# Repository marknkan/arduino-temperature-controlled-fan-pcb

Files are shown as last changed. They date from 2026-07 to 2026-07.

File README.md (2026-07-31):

# Arduino Temperature-Controlled Fan PCB

My first manufactured PCB: an Arduino Uno expansion board for a temperature-controlled DC fan with automatic and manual operating modes.

This project developed an earlier breadboard prototype into my first manufactured PCB. It brought together embedded programming, analogue sensing, PWM motor control, user inputs, LCD output, schematic capture, PCB layout, soldering, testing and hardware debugging.

Arduino Uno, Embedded C/C++, KiCad, PCB Design, PWM ADC, and Hardware Debugging

Status — Version 1 tested: The PCB was successfully designed, manufactured and assembled. The controls and several interfaces worked, while bring-up exposed three hardware issues to correct in Version 2: the fan-driver routing, RGB LED pin mapping and LM35 interface

[Powered assembled PCB](docs/images/hardware/pcb-powered-on.jpg)

[Watch the Version 1 prototype demonstration] (https://github.com/marknkan/arduino-temperature-controlled-fan-pcb/releases/tag/v1.0)

# Contents

- Project objectives

- Operating modes

- Hardware

- Main pin assignments

- PCB development

### Schematic

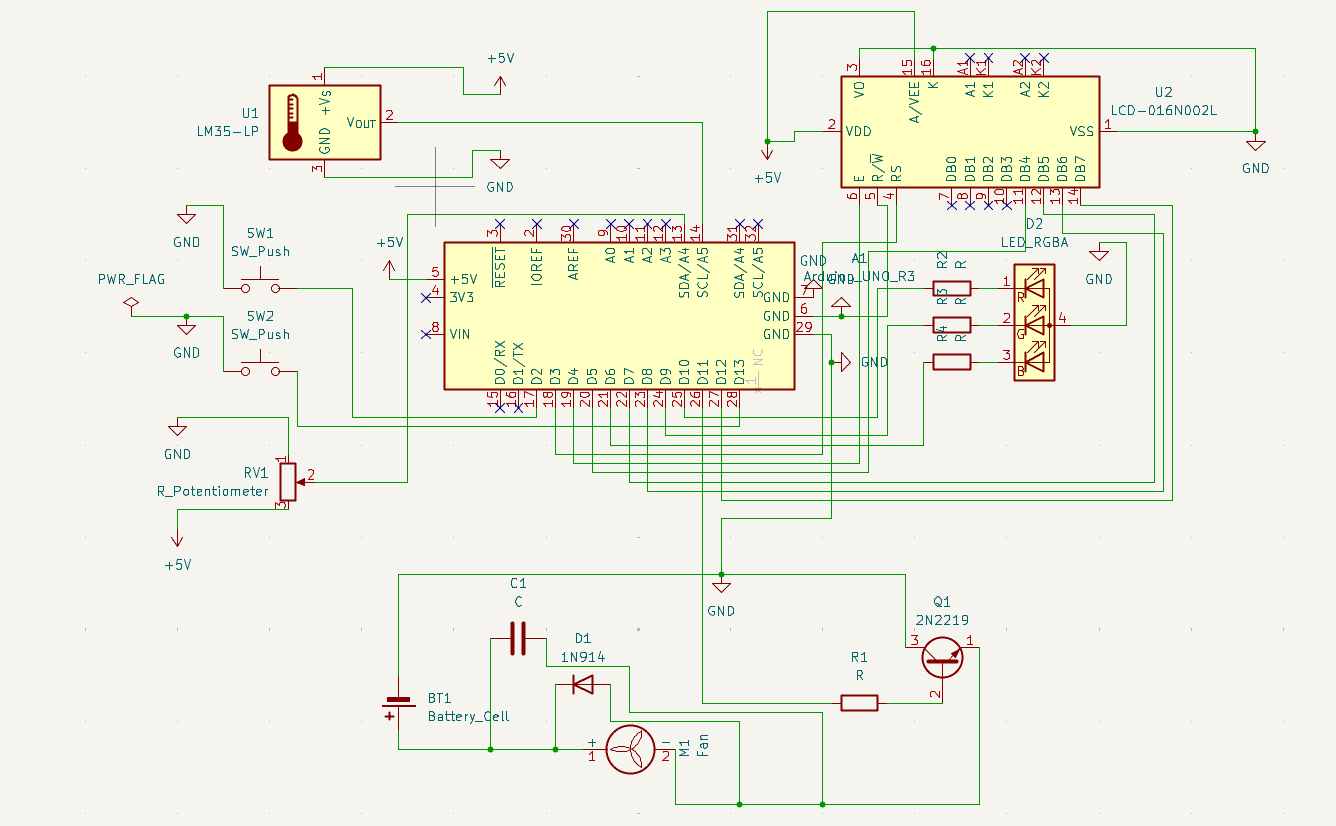
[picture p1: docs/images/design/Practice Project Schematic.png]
KiCad schematic


### PCB layout

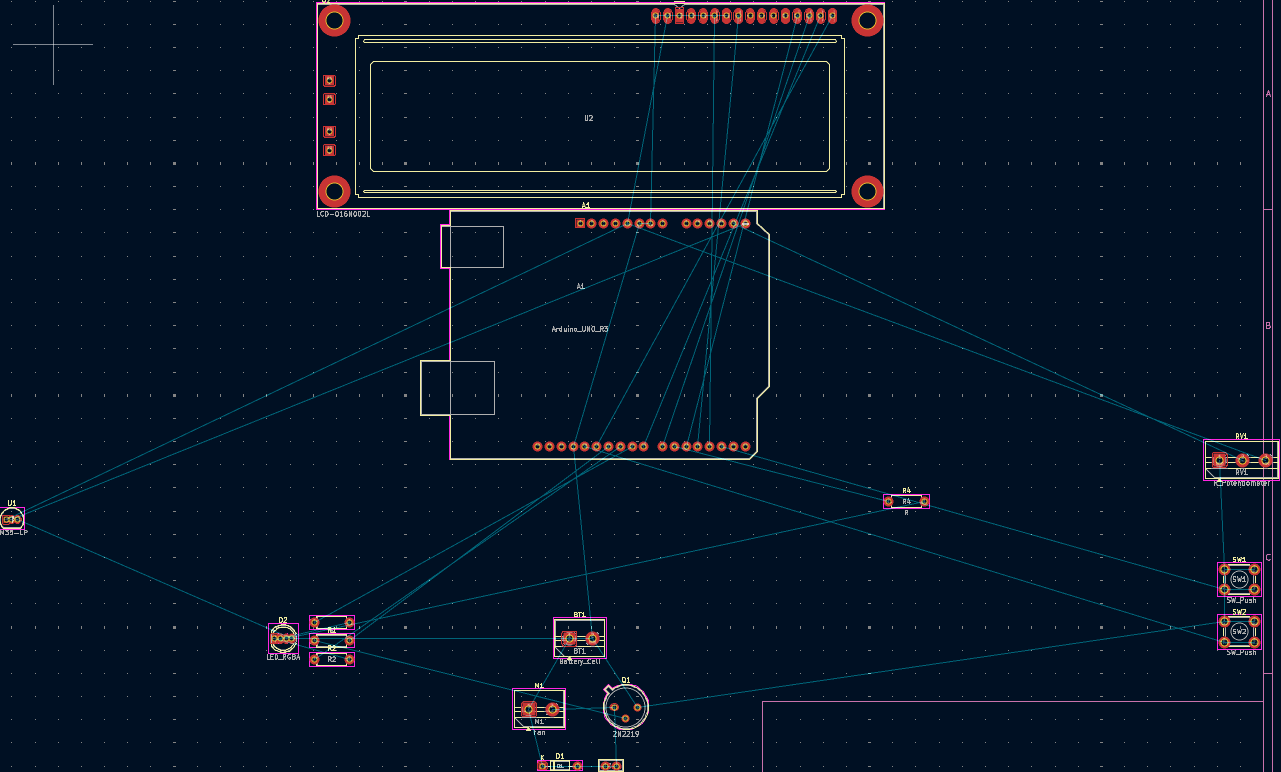
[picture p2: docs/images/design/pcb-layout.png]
PCB layout


### 3D render

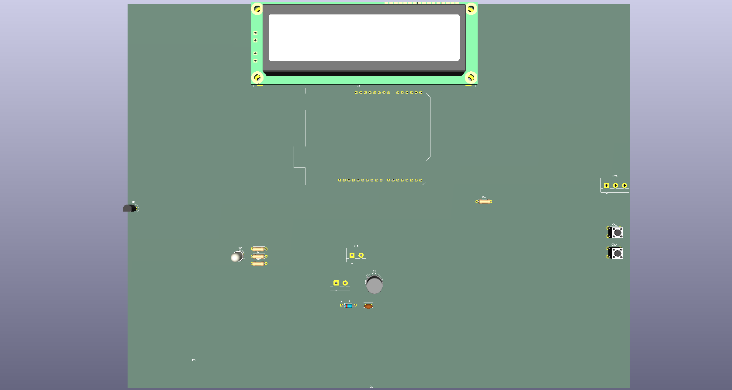
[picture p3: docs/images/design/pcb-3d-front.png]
PCB 3D render


- Firmware development

- Testing and results

- Detailed engineering test log

# What I learned

- Version 2 improvements

- Repository structure

- Project objectives

- Convert a working breadboard fan controller into a custom PCB.

- Read temperature using an LM35 analogue temperature sensor.

- Control a DC fan automatically according to temperature.

- Provide manual fan-speed control using a potentiometer.

- Display the selected mode, temperature and fan output on a 16×2 LCD.

- Use of an RGB LED to indicate operating mode and temperature range.

- Use of push buttons to change mode and return to the startup screen.

- Complete the full PCB lifecycle from schematic capture to assembly and testing.

# Operating modes

- Automatic mode

The Arduino reads the LM35 sensor and changes the requested fan speed and RGB status according to temperature:

| Temperature | Fan command | RGB indicator |
| :--- | :--- | :--- |
| Below 20 °C | Low | Blue |
| 20–28 °C | Medium | Orange/amber |
| Above 28 °C | Full | Red |

# Manual mode

The potentiometer is read through an analogue input and mapped to a PWM value from 0–255. This value controls the requested fan speed, the green LED brightness and the fan percentage shown on the LCD.

- Hardware

- Arduino Uno R3

- Custom two-layer PCB

- LM35 temperature sensor

- 16×2 HD44780-compatible LCD

- Common-cathode RGB LED and current-limiting resistors

- DC fan

- NPN transistor motor-driver stage

- Flyback diode

- Motor suppression capacitor

- Potentiometer

- Two push buttons

- External battery supply

- Screw terminals and Arduino stacking headers

# Main pin assignments

| Function | Arduino pin |
| :--- | :--- |
| Mode button | D2 |
| LCD RS | D3 |
| LCD Enable | D4 |
| LCD D4 | D5 |
| RGB blue | D6 |
| LCD D5 | D7 |
| LCD D6 | D8 |
| RGB red/green channels | D9 and D10 |
| Fan PWM command | D11 |
| LCD D7 | D12 |
| Reset/startup button | D13 |
| LM35 output | A0 |
| Potentiometer | A4 |

# Revision note:
Early firmware used A5 for the LM35 before PCB testing moved it to A0. The red and green RGB assignments were also swapped between D9 and D10 during diagnosis. These changes are retained in the test history below.

# PCB development
1. PCB development

2. The board was designed in KiCad. The workflow included:

3. Schematic capture and net labelling

4. Electrical Rules Check (ERC)

5. Through-hole footprint selection

6. Component placement and board-outline creation

7. Track routing and ground-zone fills

8. Design Rules Check (DRC)

9. Gerber and drill-file generation

10. PCB manufacture

11. Through-hole assembly and soldering

12. Continuity, voltage and functional testing

The manufactured board had a clean finish, readable silkscreen and correctly aligned Arduino headers.

# Firmware development

The firmware was changed throughout bring-up so individual subsystems could be isolated and tested.

| Stage | Code change | Reason and result |
| :--- | :--- | :--- |
| Initial controller | Added automatic and manual modes, Serial selection at 9600 baud, LM35 conversion and PWM fan control | Established the working breadboard behaviour before PCB integration. |
| LCD integration | Added LiquidCrystal lcd(3, 4, 5, 7, 8, 12) and lcd.begin(16, 2) | Displayed startup, selected mode, temperature and manual speed percentage. |
| Input handling | Configured buttons D2 and D13 with active-LOW logic and a 300 ms debounce/reset delay | Enabled mode switching and return to the startup screen. |
| Manual control | Mapped potentiometer 0–1023 to PWM 0–255, then to 0–100% for the LCD | Potentiometer readings changed correctly and the manual control logic worked. |
| Automatic control | Set fan commands to 80, 180 and 255 at <20 °C, 20–28 °C and >28 °C | Preserved the three temperature bands from the breadboard system. |
| Sensor debugging | Changed the LM35 input from A5 to A0 and printed raw ADC, calculated voltage and temperature | Exposed abnormal sensor values instead of hiding them behind the temperature calculation. |
| RGB debugging | Swapped red/green assignments between D10/D9 and D9/D10; ran individual colour tests | Red and green responded, but blue remained open because of the hardware pin-order mismatch. |
| Timing adjustments | Tried 1000 ms and 1200 ms automatic delays; retained a 250 ms manual delay | Made Serial and LCD behaviour easier to observe during testing. |
| Safe reset | Set fan PWM to 0 and requested RGB white 255,255,255 before returning to startup | Fan-off logic worked in code; true white was prevented by the failed blue LED channel. |

The final repository should retain the complete Arduino source in firmware/ so the implementation can be compared with this change history.

# Testing and Results 

| Area | Result | Notes |
| :--- | :--- | :--- |
| PCB manufacture | Pass | Board quality, outline, silkscreen and header alignment were good. |
| Arduino connection | Pass | The PCB fitted and connected to the Arduino Uno through its headers. |
| Power and continuity | Pass | Key power and signal connections were checked before full testing. |
| Push buttons | Pass | Mode selection and startup/reset input were detected. |
| Potentiometer input | Pass | The analogue value changed correctly. |
| LCD interface | Partial | The display powered up, but contrast and signal problems prevented reliable text. |
| LM35 circuit | Partial | The circuit produced inconsistent analogue readings during orientation and soldering tests. |
| RGB LED | Partial | Red and green worked; a footprint-to-component mismatch prevented blue. |
| Fan-driver stage | Fail — V1 | The transistor emitter and collector were routed incorrectly for the intended low-side switch. |

# Debugging performed

- Used continuity mode to trace PCB nets and verify solder joints.

- Measured supply and analogue voltages with a multimeter.

- Checked the Arduino headers and LCD signal paths.

- Investigated LCD power, contrast and data connections.

- Removed, reoriented and resoldered the LM35 during sensor testing.

- Tested individual RGB LED channels and identified a footprint/pinout mismatch.

- Reviewed the transistor circuit and found the emitter/collector routing error.

- Reflowed joints and used solder wick and a solder sucker where required.

# Detailed engineering test log

This section preserves the numerical readings and different troubleshooting approaches used during Version 1 bring-up. Conflicting results are intentionally included because they were recorded at different stages of debugging.

<details>
<summary><strong>View detailed test measurements and troubleshooting log</strong></summary>

# Test equipment and reference values

| Item | Value or setting | Purpose |
| :--- | :--- | :--- |
| Multimeter | Continuity/resistance mode | Checking tracks, headers, solder joints and component paths |
| Multimeter | 20 V DC range | Measuring the Arduino, LCD, LM35 and PCB supply voltages |
| Arduino ADC | 10-bit, 0–1023 | Reading the LM35 and potentiometer |
| ADC reference used in firmware | 5.0 V | Converting ADC counts to voltage |
| LM35 scale factor | 10 mV/°C | Converting sensor output voltage to temperature |
| Expected LM35 room-temperature output | Approximately 0.18–0.30 V | Reference range used during diagnosis |
| Serial Monitor | 9600 baud | Viewing raw ADC, voltage, temperature and potentiometer data |
| LCD | 16 columns × 2 rows | User display |

The conversion used in the firmware was:

voltage = rawADC × (5.0 / 1023.0)
temperatureC = voltage × 100.0

An earlier temperature-monitor version expressed the same conversion as:

voltage = (5.0 / 1023.0) × rawADC
millivolts = voltage × 1000
temperatureC = millivolts / 10

# Firmware values tested

| Parameter | Value |
| :--- | :--- |
| Full fan PWM | 255 |
| Medium fan PWM | 180 |
| Low fan PWM | 80 |
| Fan off PWM | 0 |
| Full LED brightness | 255 |
| Potentiometer ADC input range | 0–1023 |
| Mapped manual PWM range | 0–255 |
| Mapped LCD speed range | 0–100% |
| Cold threshold | <20 °C |
| Medium-temperature range | 20–28 °C |
| Hot threshold | >28 °C |
| Amber RGB command | Red 255, Green 40, Blue 0 |
| Reset/startup RGB command | Red 255, Green 255, Blue 255 |
| Automatic-loop delays tried | 1000 ms and 1200 ms |
| Manual-loop delay | 250 ms |
| Button debounce/reset delay | 300 ms |

# LCD tests

| Test or observation | Result |
| :--- | :--- |
| LCD interface tested with LiquidCrystal lcd(3, 4, 5, 7, 8, 12) | This was the final PCB-oriented firmware mapping: RS=D3, E=D4, D4=D5, D5=D7, D6=D8, D7=D12. |
| LCD supply/header continuity | Recorded readings across tested LCD signal paths were approximately 0–0.8 Ω, supporting continuity through the PCB connections. |
| LCD power-up | The backlight powered and white character blocks appeared, showing that the module had power but was not displaying valid text. |
| Firmware/serial activity | The display later flickered in time with Serial activity. It also became dim and flashed during later attempts. |
| Contrast pin approach | LCD pin 3 (VO) was investigated because no dedicated contrast potentiometer was fitted to the PCB. |
| Temporary contrast tests proposed | VO directly to GND or through approximately 1 kΩ; these were diagnostic approaches and were not preserved as confirmed final measurements. |
| LCD power reference used for diagnosis | Pin 1=GND, pin 2=5 V, pin 5 (RW)=GND, pin 15=5 V, pin 16=GND. |
| Startup text in firmware | Line 1: Auto or Manual?; line 2: Pick :). |
| Mode screens in firmware | (Automatic Mode) with Degrees (C):; (Manual Mode) with Speed: <0–100>%. |

# LM35 temperature-sensor tests

| Test stage | Recorded result | Interpretation/action |
| :--- | :--- | :--- |
| Original PCB definition | LM35-LP U1, TO-92_Inline; Pad 1=+5 V, Pad 2=VOUT, Pad 3=GND | The footprint’s flat-face edge was shown at the bottom, creating an orientation check against the real part. |
| Firmware revisions | Early versions used A5; later PCB testing used A0 | This A5/A0 mismatch was tracked as a firmware/documentation conflict. |
| First abnormal result | Approximately 70 °C | Far above room temperature, so the sensor orientation, pin mapping, soldering and ADC input were investigated. |
| Later abnormal result | Approximately 200 °C | Confirmed that the analogue signal was still invalid rather than representing room temperature. |
| Serial debug result | Raw ADC=471 | Used to calculate the corresponding input voltage. |
| Calculated ADC voltage | 471 × (5/1023) = 2.302 V | Much higher than the expected LM35 room-temperature output. |
| Calculated temperature | 2.302 V × 100 = 230.2 °C | Demonstrated that the code conversion was consistent with the voltage, but the input signal was incorrect. |
| Later A0 measurement | Approximately 0.03 V | Too low for the expected room-temperature LM35 output. |
| LM35 middle/output pin measurement | Approximately 1.25 V | Equivalent to roughly 125 °C using the LM35 scale; still invalid for room temperature. |
| Nearby header/supply-gap measurement | Approximately 4.67 V | Confirmed that a near-5 V supply was present at the tested header location. |
| Expected room-temperature reference | Approximately 0.18–0.30 V | Equivalent to roughly 18–30 °C. None of the abnormal readings consistently matched this range. |
| Sensor installed | Arduino sometimes appeared as COM9 | The sensor’s presence coincided with a changed/unstable port during one stage of testing. |
| Sensor removed | Arduino appeared as COM11 | Removing the LM35 restored the expected connection during that attempt. |
| After removal/resoldering | COM11 operation later returned | The COM-port issue was eventually cleared, but the sensor output remained unreliable. |
| Orientation attempt | LM35 was removed, flipped/reoriented and soldered again | The same general fault remained, reducing confidence that orientation alone was the cause. |
| Replacement approach | A bare LM35 was tried | This ruled out relying only on the original sensor/component form. |
| Hole-clearing issue | Desoldered holes filled with solder | Wick/sucker and reheating were used until the sensor could be inserted again. |
| Unsoldered insertion test | LM35 could be inserted after the holes were cleared | Used as another contact/orientation test before final soldering. |

The usual LM35 TO-92 reference used during diagnosis, with the flat face toward the viewer, was:

Left: +5 V    Middle: VOUT    Right: GND

This was checked against the exact part and PCB footprint rather than assumed to be universally correct.

# RGB LED tests

| Test or observation | Result |
| :--- | :--- |
| Physical LED type | 5 mm diffused common-cathode RGB LED |
| Physical orientation observed | Flat side facing right; longest lead expected to be the common cathode/GND. |
| PCB pad order | Pad 1=Red, Pad 2=Green, Pad 3=Blue, Pad 4=GND |
| Suspected physical LED order | Red, Green, GND, Blue |
| Red-channel continuity/function | Continuity/function was obtained. |
| Green-channel continuity/function | Continuity/function was obtained. |
| Blue-channel continuity test | OL / open circuit was observed. |
| Visual functional result | Red and green worked; blue did not. White, which requires all three channels, therefore could not display correctly. |
| Earlier firmware mapping | Red=D10, Green=D9, Blue=D6 |
| Later test mapping | Red=D9, Green=D10, Blue=D6 |
| Manual-mode target | Green brightness follows the potentiometer PWM value from 0–255. |
| Automatic-mode target | Blue below 20 °C; amber from 20–28 °C; red above 28 °C. |
| Mechanical inspection | Bent/soldered LED leads were checked because adjacent pins might have touched. |
| Diagnostic approaches | Individual-channel sketches, red/green pin swapping, reflowing solder joints and continuity tests through the resistors/tracks were used. |

# Potentiometer and button tests

| Test | Result |
| :--- | :--- |
| Potentiometer input | Connected to A4; ADC range 0–1023 was mapped to PWM 0–255. |
| LCD manual output | PWM 0–255 was mapped again to 0–100%. |
| Potentiometer hardware | The physical potentiometer did not match the selected footprint cleanly and was trimmed/adjusted to fit. |
| Potentiometer response | Analogue values changed, confirming that the control input worked. |
| Mode button | D2, configured with INPUT_PULLUP; active state=LOW. |
| Second/reset button | D13, active state=LOW. |
| Mode action | Toggled the manualMode Boolean after a 300 ms debounce delay in one firmware version. |
| Reset action | Set fan PWM to 0, commanded RGB 255,255,255, waited 300 ms, and returned to the startup selection. |
| Functional result | Both mode/reset button functions were detected during testing. |

# Motor, transistor and power tests

| Test or design review | Result |
| :--- | :--- |
| Motor PWM pin | Arduino D11 |
| Intended driver | 2N2222 NPN low-side switch |
| Intended power path | Battery positive → fan positive; fan negative → transistor collector; transistor emitter → GND/battery negative |
| Intended control path | Arduino D11 → base resistor → transistor base |
| Grounding requirement | Arduino GND and external battery negative must share a common ground. |
| Supplies considered/tried | Initially a 9 V battery; later a switched 4×AA battery holder with rechargeable cells. |
| Fan command values | Off=0, low=80, medium=180, full=255 |
| Terminal inspection | Fan/battery wires were found loose in the screw terminals during bring-up and required reseating/tug checking. |
| Driver design review | The PCB emitter/collector routing did not implement the intended low-side switch correctly. |
| Functional result | The V1 fan-driver stage did not operate successfully from the assembled PCB. |
| Conclusion | Because the copper routing was wrong, repeated firmware changes could not correct the hardware fault. |

# Arduino and PCB interconnection tests

| Test | Result |
| :--- | :--- |
| Arduino stacking headers | Soldered and the PCB was fitted directly onto the Arduino Uno. |
| Header alignment | Mechanically aligned with the Uno and the manufactured board fitted successfully. |
| Power-up | Board and LCD received power without an immediate destructive failure. |
| Continuity testing | Used across LCD nets, RGB resistors/tracks, ground paths and header connections. |
| Solder repair methods | Joint reflow, added flux, solder wick, solder sucker and hole clearing. |
| KiCad checks before manufacture | ERC and DRC completed; the PCB update reported 0 warnings and 0 errors. |
| Key lesson | 0 ERC/DRC errors confirmed rule compliance, but did not detect incorrect real-component pin mapping or the transistor circuit-design error. |

# Approaches discussed but not recorded as completed measurements

The following were valid troubleshooting proposals, but no final numerical result was preserved. They are separated to avoid presenting suggestions as measured evidence:

- Testing LCD VO directly at GND and through approximately 1 kΩ.

- Confirming every LCD supply pin with an exact 5.00 V measurement.

- Testing the fan independently by connecting it directly to the external battery.

- Measuring transistor base, collector and emitter voltages while commanding PWM 0 and 255.

- Testing each RGB colour with a standalone current-limited supply.

- Rebuilding the LM35 circuit fully on a breadboard and comparing its output with the PCB.

- Substituting another known-good LM35 and repeating the same voltage measurements.

</details>

# What I learned

- How to move from a breadboard prototype to a manufactured PCB.

- How schematic symbols, footprints and real component pinouts must be verified against datasheets.

- How to use ERC and DRC without treating a clean result as proof that the circuit itself is correct.

- How an NPN transistor should be connected as a low-side motor switch.

- Why component orientation, test points and accessible connectors matter during bring-up.

- How to perform staged power-up, continuity and voltage testing.

- How hardware faults can appear to be software faults, and vice versa.

- How to document failed tests and turn them into specific design changes.

# Version 2 improvements

- Correct the transistor emitter/collector routing.

- Verify every symbol-to-footprint pin mapping against the component datasheet.

- Use an RGB LED footprint that matches the exact physical pin order.

- Add a socket or removable header for the LM35.

- Improve LCD contrast control and connector labelling.

- Add clearly labelled test points for power, ground, sensor output and PWM.

- Improve component spacing and keep parts farther from the board edge.

- Review motor-current requirements and select the driver stage accordingly.

- Repeat schematic peer review, ERC, DRC and bench validation before manufacture.
├── firmware/          # Arduino source code
├── hardware/
│   ├── kicad/         # KiCad schematic and PCB files
│   ├── gerbers/       # PCB manufacturing files
│   └── bom/           # Bill of materials
├── docs/
│   ├── images/        # Project and testing photographs
│   └── testing/       # Measurements and test notes
├── LICENSE
└── README.md

# Author
# Mark Nkan
- Electrical and Electronic Engineering student interested in embedded systems, PCB design, control systems and hardware development.

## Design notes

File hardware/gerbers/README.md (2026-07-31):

# Gerber Manufacturing Files

This folder contains the Gerber and drill files generated from Version 1 of the Arduino temperature-controlled fan PCB.

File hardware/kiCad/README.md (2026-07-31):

# KiCad Design Files

This folder contains the schematic and PCB-layout source files for the Arduino temperature-controlled fan controller.

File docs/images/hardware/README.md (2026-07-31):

# Hardware Images

Physical photographs of the assembled Arduino fan-controller PCB and testing setup.

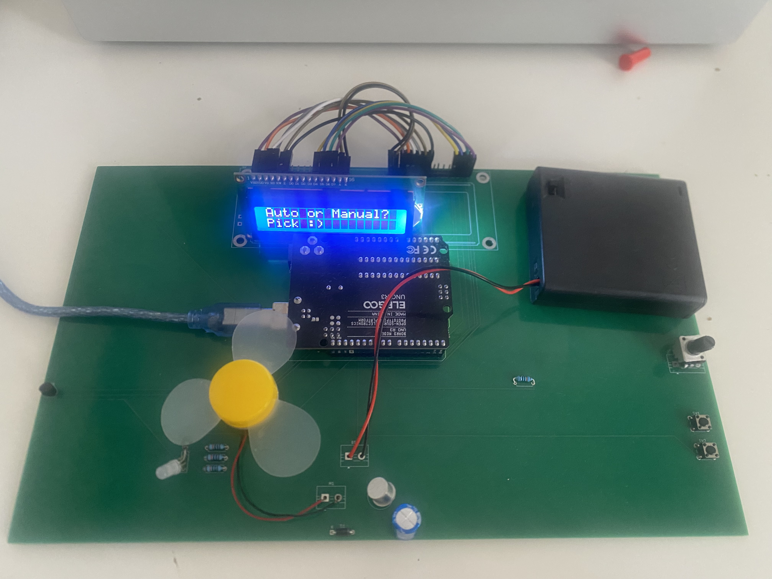
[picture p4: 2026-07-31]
docs/images/hardware/pcb-powered-on.jpg.jpg

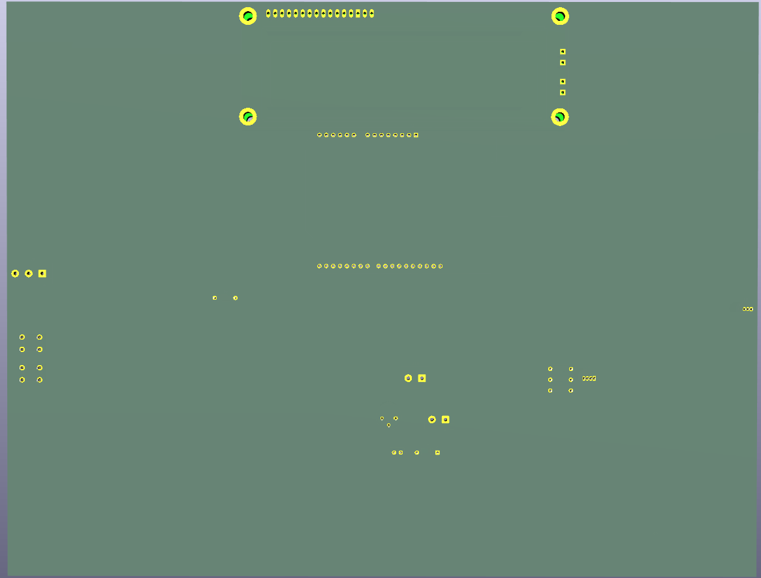
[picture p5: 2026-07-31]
docs/images/design/pcb-3d-back.png

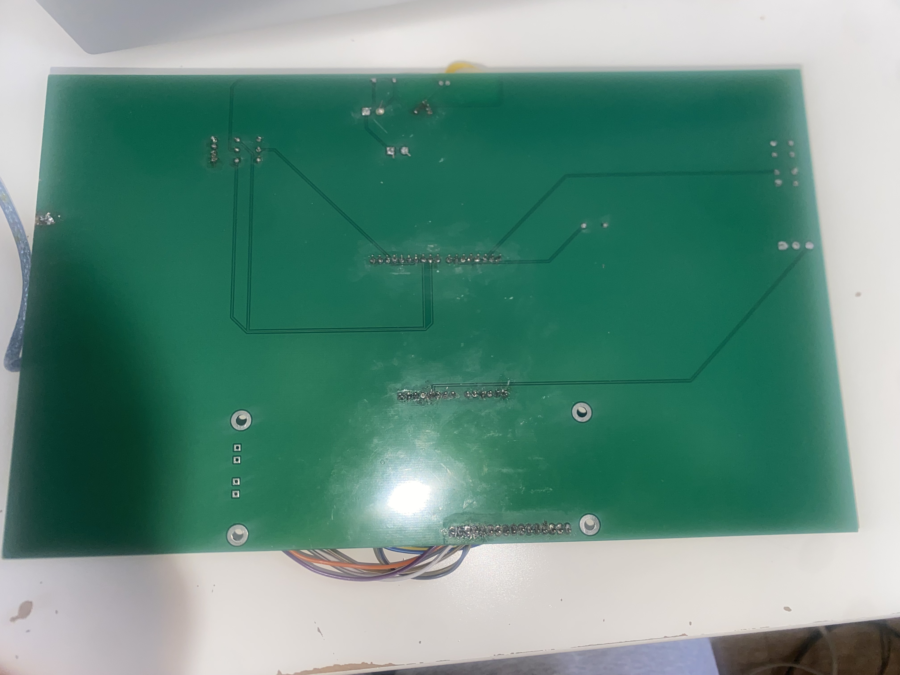
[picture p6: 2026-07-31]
docs/images/hardware/pcb-powered-on-opposite-side.jpg.jpg

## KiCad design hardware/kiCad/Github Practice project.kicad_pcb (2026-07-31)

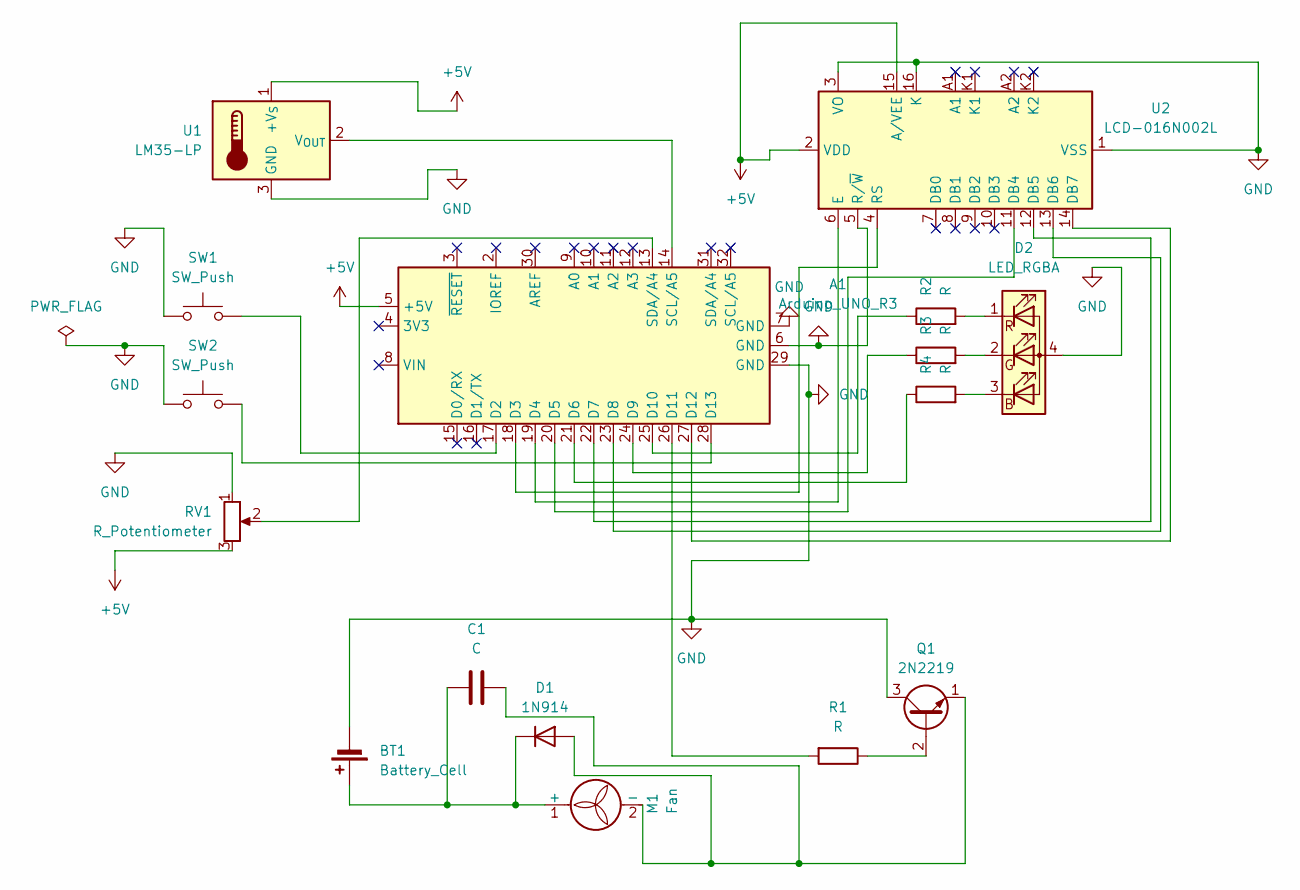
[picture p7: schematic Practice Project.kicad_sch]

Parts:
A1: Arduino_UNO_R3
BT1: Battery_Cell; TerminalBlock_MaiXu_MX126-5.0-02P_1x02_P5.00mm
C1: C; C_Disc_D5.0mm_W2.5mm_P2.50mm
D1: 1N914; D_DO-35_SOD27_P7.62mm_Horizontal
D2: LED_RGBA; PinHeader_1x04_P2.54mm_Vertical
M1: Fan; TerminalBlock_MaiXu_MX126-5.0-02P_1x02_P5.00mm
Q1: 2N2219; TO-39-3
R1, R2, R3, R4: R; R_Axial_DIN0207_L6.3mm_D2.5mm_P7.62mm_Horizontal
RV1: R_Potentiometer; TerminalBlock_MaiXu_MX126-5.0-03P_1x03_P5.00mm
SW1, SW2: SW_Push; SW_PUSH_6mm
U1: LM35-LP; TO-92_Inline
U2: LCD-016N002L

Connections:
+5V: A1.5 (+5V), RV1.3, U1.1 (+V_{S}), U2.2 (VDD), U2.15 (A/VEE)
GND: A1.6 (GND), A1.7 (GND), A1.29 (GND), BT1.2 (-), D2.4 (A), Q1.3 (C), RV1.1, SW1.1, SW2.1, U1.3 (GND), U2.1 (VSS), U2.3 (VO), U2.5 (R/~W), U2.16 (K)
unnamed: A1.17 (D2), SW1.2
unnamed: A1.18 (D3), U2.4 (RS)
unnamed: A1.19 (D4), U2.6 (E)
unnamed: A1.20 (D5), U2.11 (DB4)
unnamed: A1.21 (D6), R4.1
unnamed: A1.22 (D7), U2.12 (DB5)
unnamed: A1.23 (D8), U2.13 (DB6)
unnamed: A1.24 (D9), R3.1
unnamed: A1.25 (D10), R2.1
unnamed: A1.26 (D11), R1.2
unnamed: A1.27 (D12), U2.14 (DB7)
unnamed: A1.28 (D13), SW2.2
unnamed: A1.13 (SDA/A4), RV1.2
unnamed: BT1.1 (+), C1.1, D1.1 (K), M1.1 (+)
unnamed: C1.2, D1.2 (A), M1.2 (-), Q1.1 (E)
unnamed: D2.3 (BK), R4.2
unnamed: D2.2 (GK), R3.2
unnamed: D2.1 (RK), R2.2
unnamed: Q1.2 (B), R1.1
unnamed: A1.14 (SCL/A5), U1.2 (V_{OUT})

Board: 2 copper layers, 16 parts (0 on the bottom side), 22 nets, no tracks yet.

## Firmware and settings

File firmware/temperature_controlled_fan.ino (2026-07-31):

// Library Installation // 
#include <LiquidCrystal.h>

// LCD Pin Variables //
const int RS = 3;
const int E = 4;
const int D4 = 5;
const int D5 = 7;
const int D6 = 8;
const int D7 = 12;

// Enabling LiquidCrystal // 
LiquidCrystal lcd(RS, E, D4, D5, D6, D7);

// Hardware / Pin Variable Settings //
const int buttonPin = 2; 
const int buttonPin2 = 13; 
const int RGBred = 9; 
const int RGBgreen = 10; 
const int RGBblue = 6; 
const int motorPin = 11; 
const int tempSensor = A0; 
const int potPin = A4; 

// Motor Speed Variables //
const int fspinSpeed = 255; 
const int mspinSpeed = 180;
const int lspinSpeed = 80; 
const int xspinSpeed = 0; 

// LED Brightness Variables //
const int Fbrightness = 255; 

// Input / Output Variables //
int buttonRead; 
int buttonRead2; 
int readValue; 
float Volts; 
int tempConvert; 
int Temperature; 
int potRead; 
int potWrite;
String myMode;

// Mode Variables //
bool manualMode = true;
int speedPercent; 


void setup() {
  // Serial Communication Initialisation //
  Serial.begin(9600); 

  // Output Device Initialisation // 
  pinMode(motorPin, OUTPUT); 

  // Sensor Initialisation // 
  pinMode(tempSensor, INPUT); 

  // RGB LED Initialisation // 
  pinMode(RGBred, OUTPUT); 
  pinMode(RGBgreen, OUTPUT);
  pinMode(RGBblue, OUTPUT); 

  // Button Initialisation // 
  pinMode(buttonPin, INPUT_PULLUP); 
  pinMode(buttonPin2, INPUT_PULLUP); 

  // Potentiometer Initilisation 
  pinMode(potPin, INPUT); 

  // LCD Initilisation //
  lcd.begin(16,2);
}

void loop() {
  // Start-Up Screen //
  lcd.clear();
  lcd.setCursor(0,0);
  lcd.print("Auto or Manual?");
  lcd.setCursor(0, 1);
  lcd.print("Pick :)");

  // System Idle RGBLED Colour //
  analogWrite(RGBgreen, 255);
  analogWrite(RGBblue, 255);
  analogWrite(RGBred, 255);

  // User Mode Selection // 
  Serial.println("Which mode would you would you like (Automatic? / Manual?)"); // Ask User for Input
  while(Serial.available()==0) { }
  myMode = Serial.readString(); // Gets User Input 
  myMode.trim();

  // Mode Selection Logic // 
  if(myMode == "Automatic" || myMode == "automatic" || myMode == "Auto" || myMode == "auto" ) {
    manualMode = false;
  }

  
  else if(myMode == "Manual" || myMode == "manual" || myMode == "Man" || myMode == "man") {
      manualMode = true;
  }
  while(true){
  // Button State Reading //
  buttonRead = digitalRead(buttonPin);
  buttonRead2 = digitalRead(buttonPin2);
  
  // Mode Toggle Button // 
  if(buttonRead == LOW) {
    manualMode = !manualMode;
    delay(300);
  }
  
  // System Reset / Exit Button //
  if(buttonRead2 == LOW) {
    analogWrite(motorPin, 0);
    analogWrite(RGBgreen, 255);
    analogWrite(RGBblue, 255);
    analogWrite(RGBred, 255);
    delay(300);
    break;
  }
  // Manual Mode Operation // 
  if(manualMode){

    // Potentiometer to PWM Conversion // 
    buttonRead = digitalRead(buttonPin);
      potRead = analogRead(potPin); 
      potWrite = map(potRead, 0, 1023, 0, 255); 

      // PWM to Percentage Conversion //
      speedPercent = map(potWrite, 0, 255, 0, 100); 

      // Motor Control // 
      analogWrite(motorPin, potWrite); 

      // Manual Mode RGB Indicator //
      analogWrite(RGBgreen, 255 - potWrite);
      analogWrite(RGBblue, 255);
      analogWrite(RGBred, 255);

      // Manual Mode LCD Display //
      lcd.setCursor(0,0);
      lcd.print("(Manual Mode)");
      lcd.print("    ");
      Serial.print("Potentiometer Read Value: ");
      lcd.setCursor(0,1);
      lcd.print("Speed: ");
      lcd.print(speedPercent);
      lcd.print("%");
      lcd.print("        ");
      // Serial Monitor Debug Output // 
      Serial.println(potRead);
      Serial.println(" ");
      delay(250);
  }
  // Automatic Mode Conversion //
  else{
  // Temperature Sensor Conversion // 
  readValue = analogRead(tempSensor);

  Volts = readValue * (5.0 / 1023.0);

  float temperatureC = Volts * 100.0;

  // Automatic Mode LCD Display //
  lcd.setCursor(0, 0);
  lcd.print("(Automatic Mode)");
  lcd.setCursor(0, 1);
  lcd.print("Degrees (C): ");
  lcd.print(temperatureC, 1);
  lcd.print("   ");

  // Serial Monitor Temperature Output // 
  Serial.print("Raw ADC: ");
  Serial.println(readValue);

  Serial.print("Voltage: ");
  Serial.println(Volts, 3);

  Serial.print("Temperature: ");
  Serial.println(temperatureC, 1);

  delay(1000);

  // Temperature Control Logic //

  // Cool Temperature Range // 
  if(temperatureC < 20.) { 
    analogWrite(RGBred, 0);
    analogWrite(RGBgreen, 0);
    analogWrite(RGBblue, Fbrightness);
    analogWrite(motorPin, lspinSpeed);

  }
  // Warm Temperature Range //
  else if(temperatureC >= 20. && temperatureC <= 28. ) {
    analogWrite(RGBred, Fbrightness);
    analogWrite(RGBgreen, 40);
    analogWrite(RGBblue, 0);
    analogWrite(motorPin, mspinSpeed);

  }
  // Hot Temperature Range // 
  else{
    analogWrite(RGBred, Fbrightness);
    analogWrite(RGBgreen, 0);
    analogWrite(RGBblue, 0);
    analogWrite(motorPin, fspinSpeed);
  }
  
  }

  
  }
  }

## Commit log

2026-07-31 Add Arduino fan controller firmware
2026-07-31 Create kiCad hardware folder
2026-07-31 Add KiCad schematic and PCB design files
    [Github Practice project.kicad_pcb, Practice Project.kicad_sch]
2026-07-31 Add KiCad design images
2026-07-31 Add assembled PCB photographs
2026-07-31 Create Gerber manufacturing folder
2026-07-31 Add PCB manufacturing files
